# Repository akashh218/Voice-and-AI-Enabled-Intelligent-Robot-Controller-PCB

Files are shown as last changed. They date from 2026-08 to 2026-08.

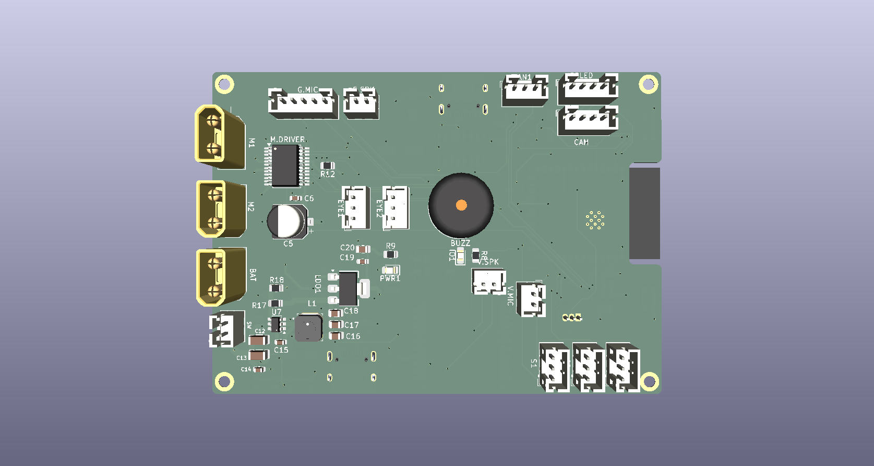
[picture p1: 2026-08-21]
Robot Controller PCB/Back.png

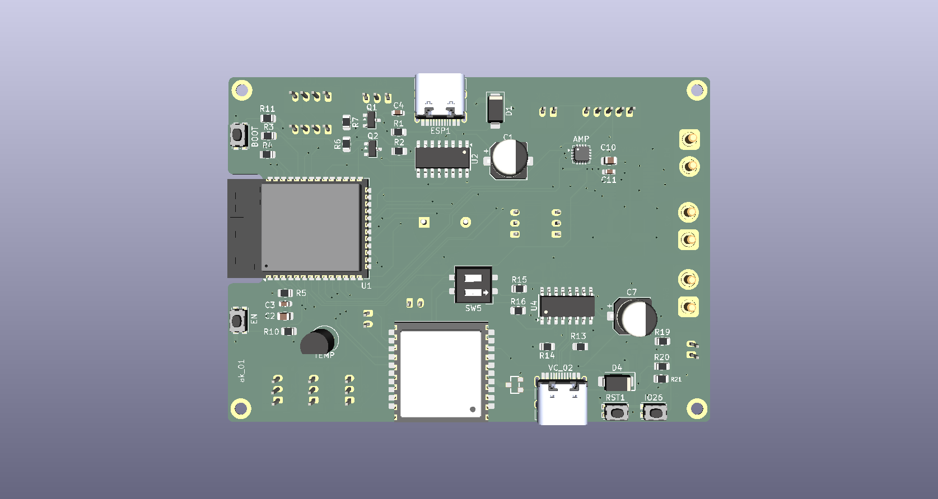
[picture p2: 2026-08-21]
Robot Controller PCB/Front.png

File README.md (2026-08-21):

# Voice and AI-Enabled Intelligent Robot Controller PCB

A custom **4-layer embedded robotics controller PCB** designed for a multifunctional voice-interactive robot. The board integrates motor control, servo control, voice recognition, AI audio interaction, environmental monitoring, RGB indication, and dedicated interfaces into a compact custom-designed PCB.

## Features

* **ESP32-based main controller**
* **Dual DC motor control** using TB6612FNG
* **3 servo motor interfaces** for robotic movement and hand mechanisms
* **VC-02 AI Thinker voice recognition module** for offline voice commands
* **ICS-43434 digital microphone** for AI chatbot voice input
* **MAX98357A I2S audio amplifier** for audio output
* **Gemini AI chatbot interface** for online conversational interaction
* **WS2812 RGB LEDs** for status and visual indication
* **Temperature monitoring**
* **Automatic DC cooling fan control** based on temperature
* **Buzzer** for temperature and alert indication
* **USB-C programming interface** using CH340C
* Dedicated motor, servo, and system power distribution

## PCB Design

The PCB uses a **4-layer stackup**:

| Layer | Function |
| ----- | --- |
| L1 | Signal + Components |
| L2 | Solid GND Plane |
| L3 | Power Distribution  |
| L4 | Signal |

The multilayer design provides improved grounding, power distribution, signal integrity, and routing flexibility for the mixed-signal robotics system.

## Main Components

* ESP32 Controller Module
* TB6612FNG Motor Driver
* VC-02 AI Thinker Voice Recognition Module
* ICS-43434 MEMS Microphone
* MAX98357A I2S Audio Amplifier
* CH340C USB-to-UART
* WS2812 RGB LEDs
* Temperature Sensor
* DC Cooling Fan
* Buzzer
* Servo and DC Motor Connectors
* USB Type-C Connector
* Power Regulation and Filtering Components

## Applications

The controller is designed for:

* Voice-controlled robotics
* AI-assisted human-machine interaction
* Educational robotics
* Embedded AI systems
* Interactive robotic platforms
* Custom robotic control systems

## Design Tools

* **KiCad**
* Schematic Capture
* PCB Layout
* 4-Layer PCB Routing
* Design Rule Checking (DRC)
* 3D PCB Visualization

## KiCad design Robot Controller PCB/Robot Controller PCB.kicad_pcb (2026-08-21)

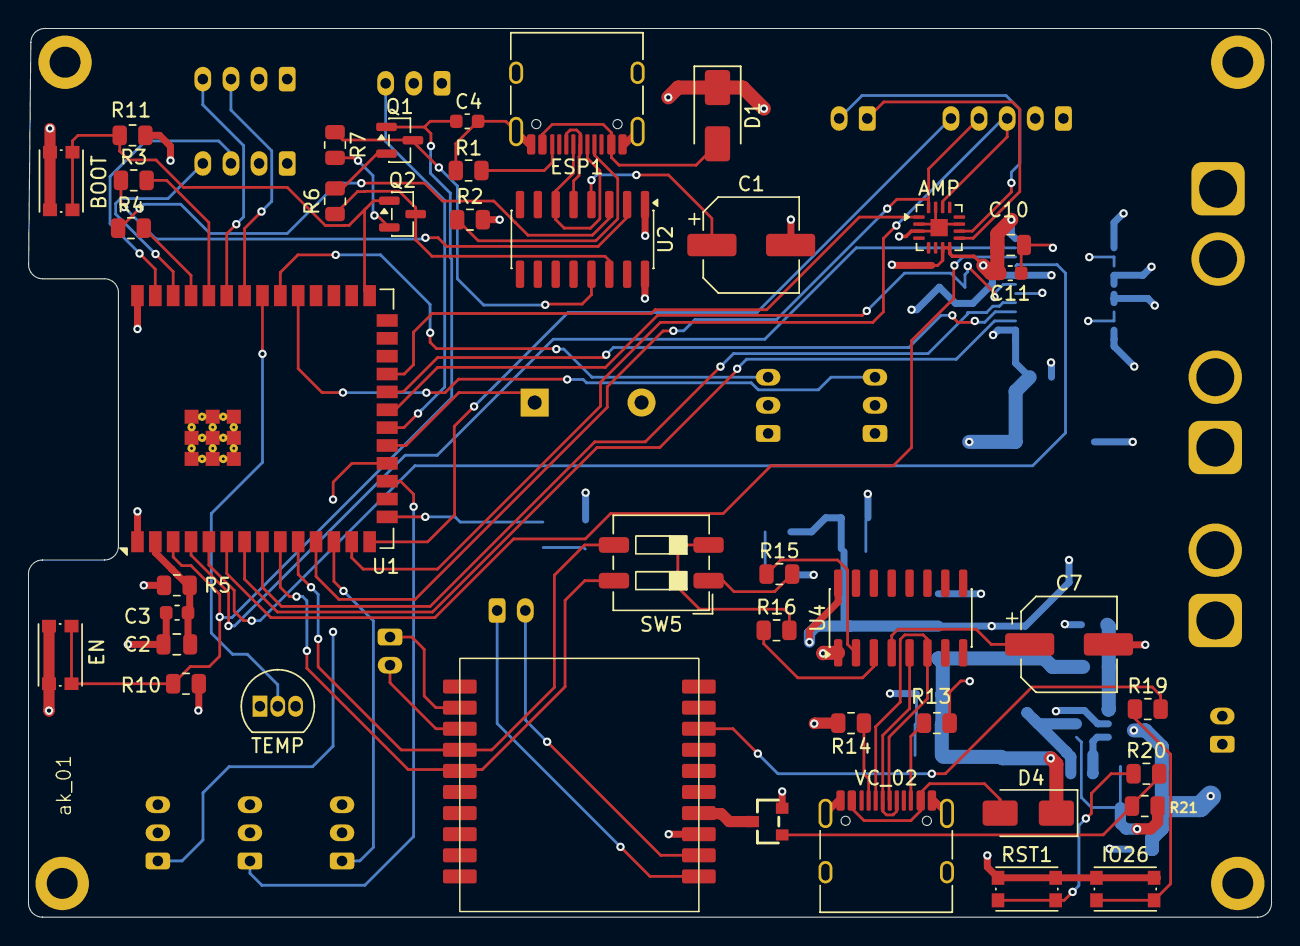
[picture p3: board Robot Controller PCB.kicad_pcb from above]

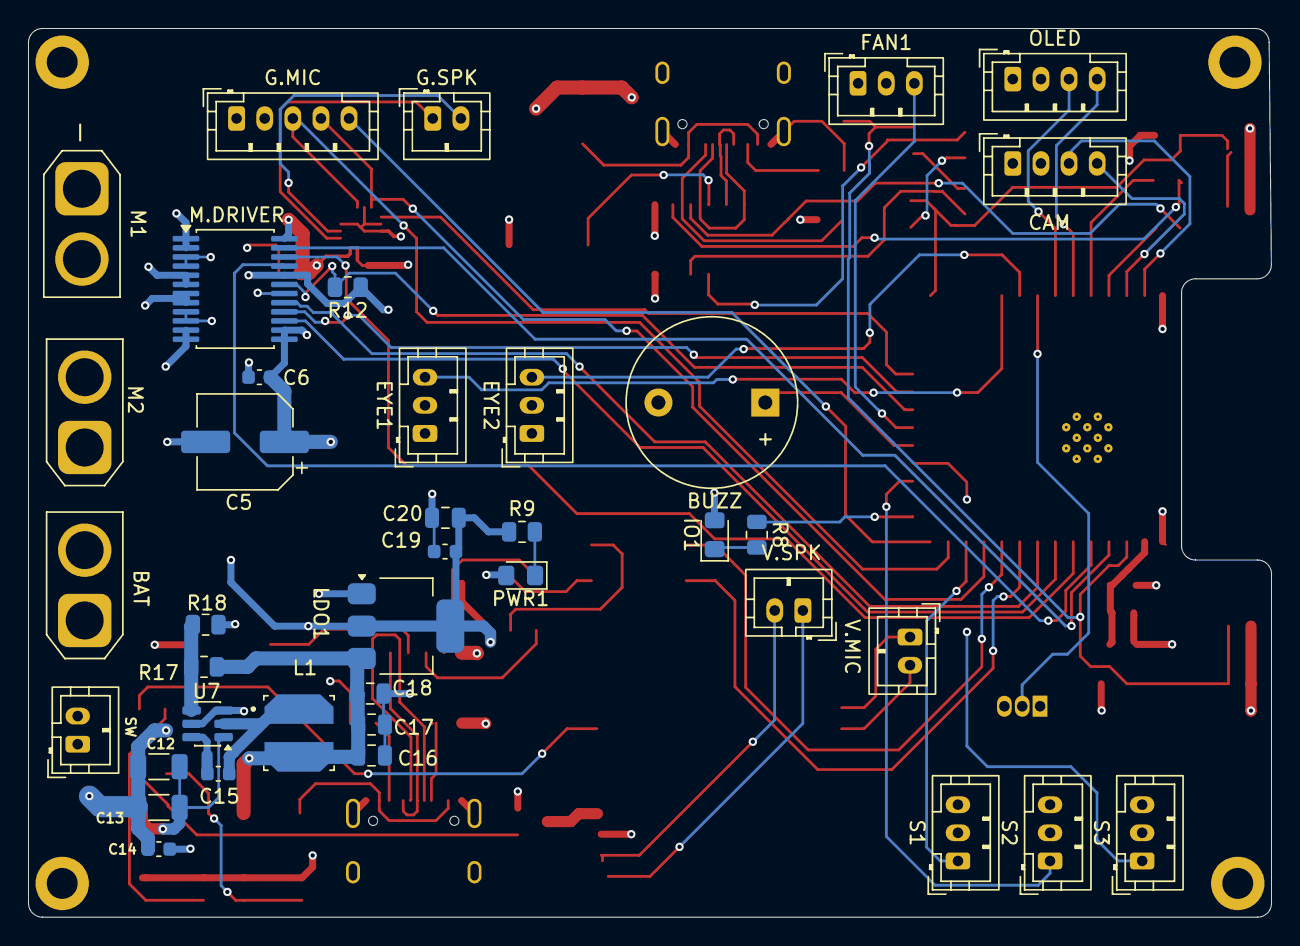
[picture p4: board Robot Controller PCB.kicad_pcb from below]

Board: 4 copper layers, 88.4 x 63.2 mm, 80 parts (39 on the bottom side), 78 nets.

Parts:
AMP: MAX98357A; TQFN-16-1EP_3x3mm_P0.5mm_EP1.23x1.23mm
BAT: 1888687; AMASS_XT30U-M_1x02_P5.0mm_Vertical
BOOT: SW_Push; SW_Push_1P1T_NO_CK_KMR2
BUZZ: Buzzer; Buzzer_12x9.5RM7.6
C1, C7: 100nF; CP_Elec_6.3x5.4
C2, C10, C16, C17, C18, C20: 10μF; C_0805_2012Metric
C3, C4, C6, C11, C14, C15, C19: 0.1μF; C_0603_1608Metric
C5: 470μF; CP_Elec_6.3x5.4
C12, C13: 22μF; C_1206_3216Metric
CAM: Conn_01x04_Pin; JST_PH_B4B-PH-K_1x04_P2.00mm_Vertical
D1, D4: D_Schottky; D_SMA
EN: SW_Push; SW_Push_1P1T_NO_CK_KMR2
ESP1: USB_C_Receptacle_USB2.0_16P; USB_C_Receptacle_HRO_TYPE-C-31-M-12
EYE1, EYE2: Conn_01x03_Pin; JST_PH_B3B-PH-K_1x03_P2.00mm_Vertical
FAN1: Conn_01x03_Pin; JST_PH_B3B-PH-K_1x03_P2.00mm_Vertical
G.MIC: Conn_01x05_Pin; JST_PH_B5B-PH-K_1x05_P2.00mm_Vertical
G.SPK: Conn_01x02_Pin; JST_PH_B2B-PH-K_1x02_P2.00mm_Vertical
IO1: LED; LED_0805_2012Metric_Pad1.15x1.40mm_HandSolder
IO26: SW_Push; SW_Push_1P1T_NO_CK_KMR2
L1: L; IND_VLCF5020T-3R3N2R0-1
LDO1: AMS1117-3.3; SOT-223-3_TabPin2
M1, M2: 1888687; AMASS_XT30U-M_1x02_P5.0mm_Vertical
M.DRIVER: TB6612FNG; SSOP-24_5.3x8.2mm_P0.65mm
OLED: Conn_01x04_Pin; JST_PH_B4B-PH-K_1x04_P2.00mm_Vertical
PWR1: LED; LED_0805_2012Metric_Pad1.15x1.40mm_HandSolder
Q1, Q2: NPN; SOT-23
R1, R2, R13, R14: 5.1K; R_0805_2012Metric
R3, R4, R15, R16, R19, R20: 470Ω; R_0805_2012Metric
R5: 0E; R_0805_2012Metric
R6, R7, R10, R11, R12, R18: 10K; R_0805_2012Metric
R8, R9: 330Ω; R_0805_2012Metric
R17: 54.1K; R_0805_2012Metric
R21: 100K; R_0805_2012Metric
RST1: SW_Push; SW_Push_1P1T_NO_CK_KMR2
S1, S2, S3: Conn_01x03_Pin; JST_PH_B3B-PH-K_1x03_P2.00mm_Vertical
SW: Conn_01x02_Pin; JST_PH_B2B-PH-K_1x02_P2.00mm_Vertical
SW5: SW_DIP_x02; SW_DIP_SPSTx02_Slide_6.7x6.64mm_W6.73mm_P2.54mm_LowProfile_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
TEMP: DS18B20; TO-92_Inline
U1: ESP32-S3-WROOM-2
U2, U4: CH340C; SOIC-16_3.9x9.9mm_P1.27mm
U5: Untitled
U7: TPS565208; SOT-23-6
U10: CJ2301; SOT23-3
V.MIC, V.SPK: Conn_01x02_Pin; JST_PH_B2B-PH-K_1x02_P2.00mm_Vertical
VC_02: USB_C_Receptacle_USB2.0_16P; USB_C_Receptacle_HRO_TYPE-C-31-M-12

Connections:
+3.3V: C19.1, C20.1, G.MIC.1, IO26.1, LDO1.2 (VO), M.DRIVER.20 (VCC), R5.1, R9.1, R10.1, R11.1, R12.1, RST1.1, TEMP.3 (V_{DD}), U2.16 (VCC), U4.16 (VCC), U10.2
+5V: AMP.7 (VDD), AMP.8 (VDD), C5.1, C6.2, C10.1, C11.2, C16.1, C17.1, C18.1, CAM.1, D1.1 (K), D4.1 (K), EYE1.1, EYE2.1, FAN1.1, L1.2, LDO1.3 (VI), M.DRIVER.13 (VM2), M.DRIVER.14 (VM3), M.DRIVER.24 (VM1), OLED.1, R17.1, S1.2, S2.2, S3.2
/esp32/BOOT: BOOT.1, Q2.1 (C), R11.2, U1.27 (IO0)
/esp32/DTR: Q1.3 (E), R7.1, U2.13 (~DTR)
/esp32/EN: C4.1, EN.1, Q1.1 (C), R10.2, U1.3 (EN)
/esp32/IO LED: R8.1, U1.15 (IO3)
/esp32/RTS: Q2.3 (E), R6.1, U2.14 (~RTS)
/esp32/UD+: ESP1.A6 (D+), ESP1.B6 (D+), U2.5 (UD+)
/esp32/UD-: ESP1.A7 (D-), ESP1.B7 (D-), U2.6 (UD-)
/esp32/URX: R3.2, U1.36 (RXD0/IO44)
/esp32/UTX: R4.2, U1.37 (TXD0/IO43)
/esp32/VDD: C2.1, C3.2, R5.2, U1.2 (3V3)
/motordriver/G.SPK+: AMP.9 (OUTP), G.SPK.1
/motordriver/G.SPK-: AMP.10 (OUTN), G.SPK.2
/motordriver/M1.A: M1.1, M.DRIVER.1 (AO1), M.DRIVER.2 (AO1)
/motordriver/M1.B: M1.2, M.DRIVER.5 (AO2), M.DRIVER.6 (AO2)
/motordriver/M2.A: M2.1, M.DRIVER.11 (BO1), M.DRIVER.12 (BO1)
/motordriver/M2.B: M2.2, M.DRIVER.7 (BO2), M.DRIVER.8 (BO2)
/vc-02/A26: R19.2, U5.8 (IOA26)
/vc-02/RST: R20.2, R21.1, U10.1
/vc-02/UD+: U4.5 (UD+), VC_02.A6 (D+), VC_02.B6 (D+)
/vc-02/UD-: U4.6 (UD-), VC_02.A7 (D-), VC_02.B7 (D-)
/vc-02/VC_VIN: U5.4 (VCC), U10.3
A1: M.DRIVER.21 (AIN1), U1.5 (IO5)
A2: M.DRIVER.22 (AIN2), U1.6 (IO6)
A.DATA: AMP.1 (DIN), U1.23 (IO21)
B1: M.DRIVER.17 (BIN1), U1.8 (IO15)
B2: M.DRIVER.16 (BIN2), U1.22 (IO14)
BCLK: AMP.16 (BCLK), G.MIC.4, U1.11 (IO18)
BUZZER: BUZZ.1 (+), U1.19 (IO11)
C.1: CAM.3, U1.39 (IO1)
C.2: CAM.4, U1.38 (IO2)
EYE1: EYE1.3, U1.31 (IO38)
EYE2: EYE2.3, U1.32 (MTCK/IO39)
FAN: FAN1.3, U1.20 (IO12)
GND: AMP.2 (GAIN_SLOT), AMP.3 (GND), AMP.11 (GND), AMP.15 (GND), AMP.17 (PAD), BAT.2, BOOT.2, BUZZ.2 (-), C1.2, C2.2, C3.1, C4.2, C5.2, C6.1, C7.2, C10.2, C11.1, C12.2, C13.2, C14.2, C16.2, C17.2, C18.2, C19.2, C20.2, CAM.2, EN.2, ESP1.A1 (GND), ESP1.A12 (GND), ESP1.B1 (GND), ESP1.B12 (GND), ESP1.SH (SHIELD), EYE1.2, EYE2.2, FAN1.2, G.MIC.2, IO1.2 (A), LDO1.1 (GND), M.DRIVER.3 (PGND1), M.DRIVER.4 (PGND1), M.DRIVER.9 (PGND2), M.DRIVER.10 (PGND2), M.DRIVER.18 (GND), OLED.2, PWR1.2 (A), R1.2, R2.2, R13.2, R14.2, R18.2, R21.2, S1.3, S2.3, S3.3, TEMP.1 (GND), U1.1 (GND), U1.40 (GND), U1.41 (GND), U2.1 (GND), U4.1 (GND), U5.3 (GND), U7.1 (GND), VC_02.A1 (GND), VC_02.A12 (GND), VC_02.B1 (GND), VC_02.B12 (GND), VC_02.SH (SHIELD)
M.DATA: G.MIC.5, U1.14 (USB_D+/IO20)
unnamed: D1.2 (A), ESP1.A4 (VBUS), ESP1.A9 (VBUS), ESP1.B4 (VBUS), ESP1.B9 (VBUS)
unnamed: D4.2 (A), VC_02.A4 (VBUS), VC_02.A9 (VBUS), VC_02.B4 (VBUS), VC_02.B9 (VBUS)
unnamed: ESP1.A5 (CC1), R2.1
unnamed: ESP1.B5 (CC2), R1.1
unnamed: IO1.1 (K), R8.2
unnamed: IO26.2, R19.1
unnamed: PWR1.1 (K), R9.2
unnamed: Q1.2 (B), R6.2
unnamed: Q2.2 (B), R7.2
unnamed: R15.2, SW5.1
unnamed: R16.2, SW5.2
unnamed: R20.1, RST1.2
unnamed: C12.1, C13.1, C14.1, SW.1, U7.3 (VIN), U7.5 (EN)
unnamed: BAT.1, SW.2
unnamed: R4.1, U2.3 (RXD)
unnamed: R3.1, U2.2 (TXD)
unnamed: C1.1, U2.4 (V3)
unnamed: R16.1, U4.3 (RXD)
unnamed: R15.1, U4.2 (TXD)
unnamed: C7.1, U4.4 (V3)
unnamed: U5.13 (MIC+), V.MIC.2
unnamed: U5.12 (MIC-), V.MIC.1
unnamed: U5.1 (SPK+), V.SPK.1
unnamed: U5.2 (SPK-), V.SPK.2
unnamed: C15.1, L1.1, U7.2 (SW)
unnamed: C15.2, U7.6 (VBST)
unnamed: R17.2, R18.1, U7.4 (VFB)
unnamed: R14.1, VC_02.A5 (CC1)
unnamed: R13.1, VC_02.B5 (CC2)
O.SCL: OLED.4, U1.35 (MTMS/IO42)
O.SDA: OLED.3, U1.34 (MTDI/IO41)
PWMA: M.DRIVER.23 (PWMA), U1.4 (IO4)
PWMB: M.DRIVER.15 (PWMB), U1.7 (IO7)
S1: S1.1, U1.12 (IO8)
S2: S2.1, U1.17 (IO9)
S3: S3.1, U1.18 (IO10)
STBY: M.DRIVER.19 (STBY), R12.2, U1.21 (IO13)
TEMP: TEMP.2 (DQ), U1.33 (MTDO/IO40)
VC-RX: SW5.4, U1.9 (IO16), U5.15 (RX1)
VC-TX: SW5.3, U1.10 (IO17), U5.14 (TX1)
WS: AMP.14 (LRCLK), G.MIC.3, U1.13 (USB_D-/IO19)
